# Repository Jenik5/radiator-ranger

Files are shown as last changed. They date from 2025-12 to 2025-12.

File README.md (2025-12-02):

# Radiátor Ranger

## 🥶➡️🔥 Chytrý termostat pro radiátorové hlavice (ESPHome)

**Radiátor Ranger** je chytrý regulátor pro radiátorové vytápění založený na ESP32-C3 a ESPHome.  
Je navržený pro termoelektrické hlavice typu **NO – normally open**, je spolehlivý, fail-safe a plně integrovatelný s Home Assistantem.

Zařízení vzniklo jako druhá generace původního domácího prototypu – tentokrát už s profesionální DPS, plnou diagnostikou a 3D tištěnou krabičkou.

---

## ✨ Hlavní vlastnosti

- Síťové napájení (bez baterií)  
- Fail-safe chování → při výpadku je radiátor *vždy plně otevřen*  
- Externí teplota z Home Assistanta  
- Automatický fallback na interní senzor  
- Detekce otevřeného okna (libovolný binární senzor z HA)  
- Ochrana proti zamrznutí  
- Režim topné sezóny  
- Boost (časovaný i trvalý), ovládaný tlačítkem  
- LED indikace stavu a chyb  
- 4 teplotní předvolby: Away, Sleep, Home, Comfort  
- Stavový výstup pro nadřazený systém (zda je potřeba topit)  
- Interní teplota radiátoru pro diagnostiku  

---

## 🧠 Jak to funguje

### Teplota  
- Primární teplotu poskytuje externí senzor z HA.  
- Při výpadku → automatický přechod na interní čidlo DS18B20.

### Otevřené okno  
- Otevření → zpoždění 2 minuty  
- Zavření → zpoždění 10 sekund  
- Při poklesu pod bezpečnou teplotu (např. 5 °C) se radiátor otevře kvůli nezámrzu.

### Topná sezóna  
- Mimo sezónu se ventil nezavírá → šetří se aktuátor i ventil.

### Stavová hlášení  
Termostat poskytuje stavy:  
*Vypnuto, Protizámrzný režim, Zapnuto, Topí, Větrání, Boost, Není topná sezóna.*

---

## 🧩 Ovládací prvky

### Tlačítko  
- krátký stisk → boost na 2 h  
- dvojstisk → trvalý boost  
- krátký stisk během boostu → vypnutí  
- dlouhý stisk → vypnutí / zapnutí termostatu

### LED  
- **zelená** – boost (blikání / trvale)  
- **červená** – chyby  
  - blikání = výpadek externího čidla  
  - trvale = výpadek interního čidla

---

## 🛠 Hardware Overview

### Schéma zapojení
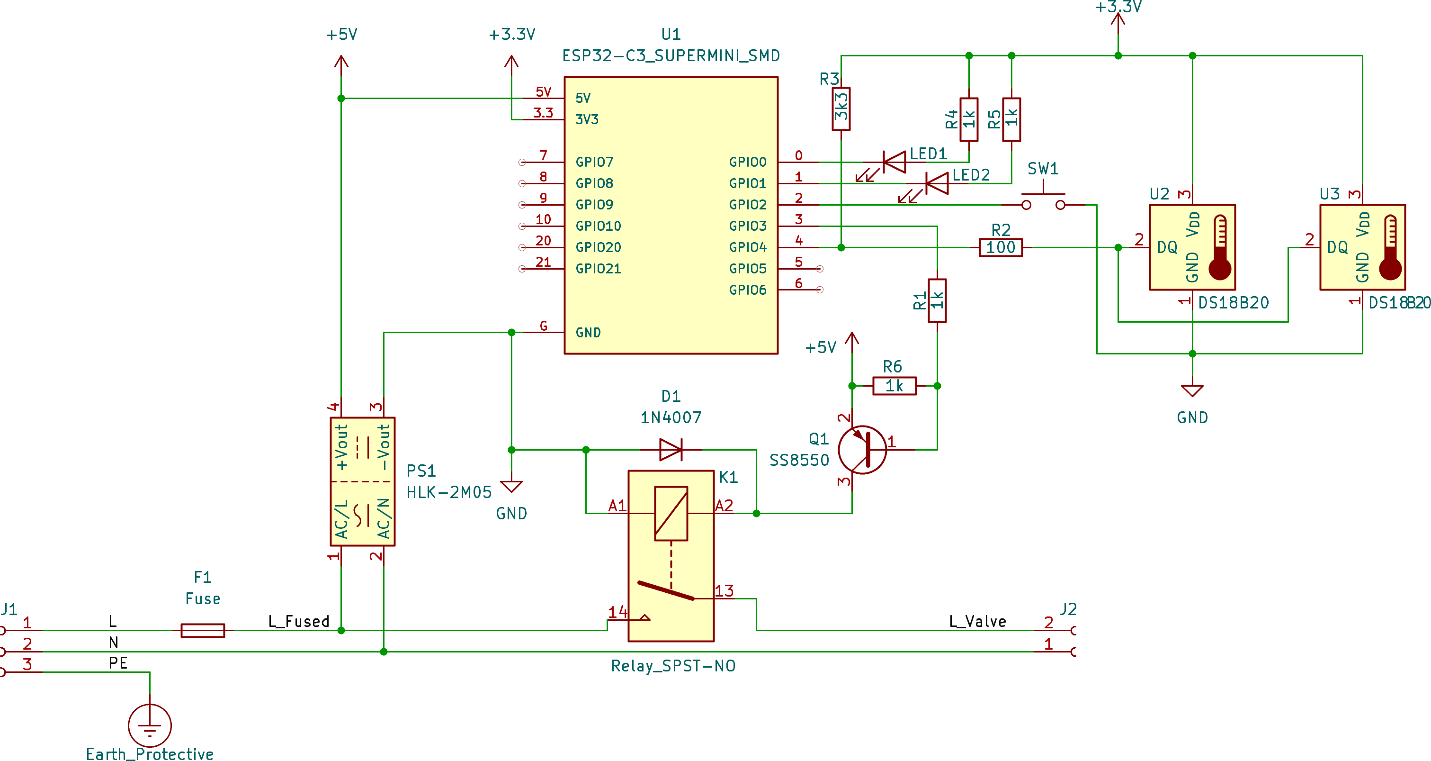
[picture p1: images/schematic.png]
Schematic


---

### Návrh DPS
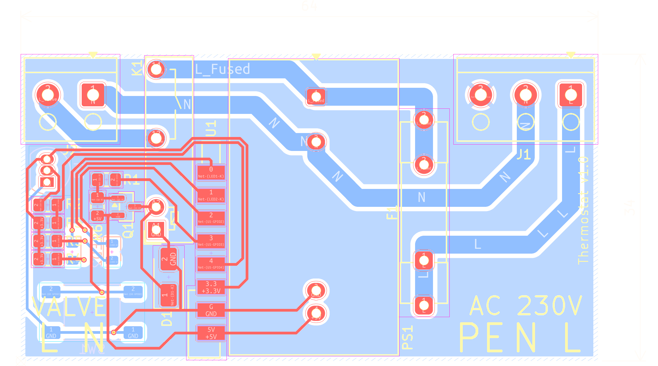
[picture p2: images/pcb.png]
PCB


---

### 3D náhled elektroniky
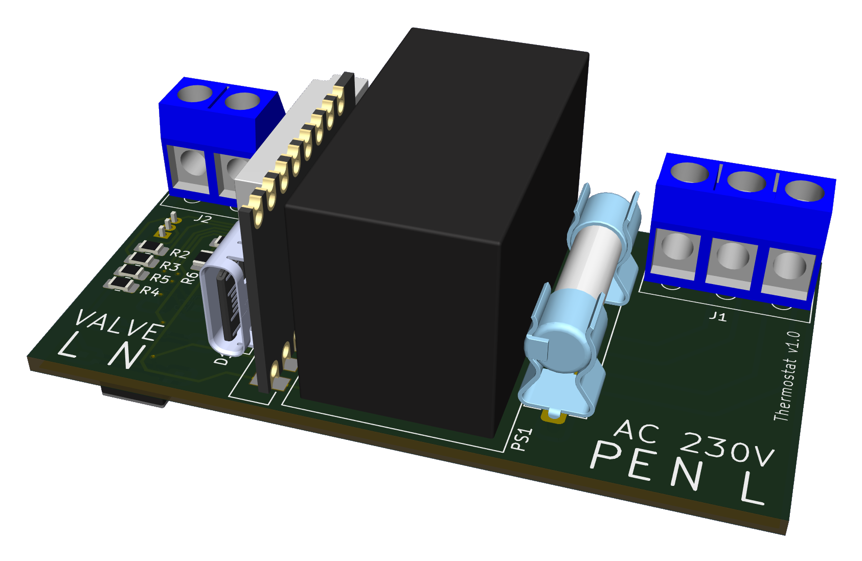
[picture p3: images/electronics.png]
Electronic module


---

### 3D tištěná krabička
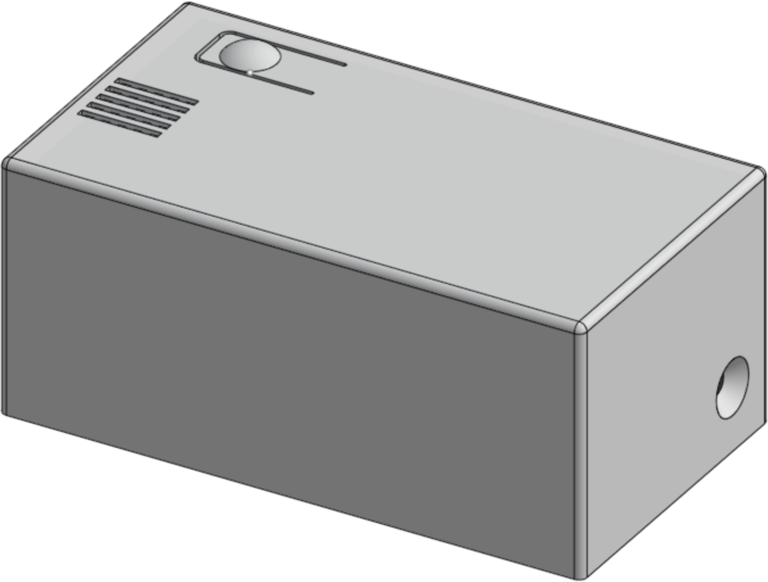
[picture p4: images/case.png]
Case


---

## 🧑‍💻 Software – ESPHome

Zařízení používá ESPHome s komponentou `climate` a vlastní sadou automatizací.

### Vybrané hodnoty konfigurace

```yaml
substitutions:
  device_internal_name: "radiator-v-predsini"
  device_suffix: "_v_predsini"
  device_friendly_name: "Radiátor v předsíni"

  device_sampling_time: "10s"

  led_green_brightness: "0.4"
  led_red_brightness: "0.6"

  dallas_diag: "0xab000000836f6328"
  dallas_fallback: "0xd500000083450828"

  external_temp_sensor: "sensor.teplomer${device_suffix}_temperature"
  heating_season_entity: "input_boolean.topna_sezona"
  open_window_entity: "input_boolean.dummy_zavreneho_okna"

  preset_temp_away: "10"
  preset_temp_sleep: "10"
  preset_temp_home: "15"
  preset_temp_comfort: "15"

  boost_minutes: "120"
  radiator_safe_temp: "5"
```

---

## 📦 Obsah repozitáře

```
/ESPHome      – ESPHome konfigurace  
/images        – obrázky pro README  
README.md      – tento soubor  
```

---

## 📝 Licence
MIT License © Jan Pruha

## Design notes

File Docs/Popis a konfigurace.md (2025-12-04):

# Radiátor Ranger – Dokumentace ovládacích prvků, senzorů a konfigurace

## Ovládací prvky

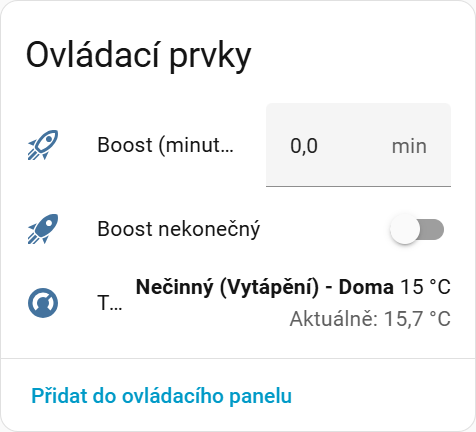
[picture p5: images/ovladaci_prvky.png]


### **Boost (minuty)**
Slouží k okamžitému přetlačení regulace termostatu a k aktivaci topení na maximální výkon po zadanou dobu.  
Během Boostu termostat dál normálně reguluje a pokud se mezitím změní režim (např. schedulerem), po ukončení Boostu bude pokračovat v aktuálně platném režimu.

### **Boost nekonečný**
Aktivuje nepřetržité nucené topení na maximální výkon, dokud není režim ručně ukončen.  
Používá se, pokud je třeba topit naplno bez časového omezení.

### **Stav topení (ovládací prvek)**
Otevře detail termostatu, který umožňuje:
- sledovat aktuální teplotu,  
- upravovat cílovou teplotu,  
- zobrazovat stav (topení / nečinný),  
- přepínat režimy.

Speciální interní stavy (např. Boost, větrání) se zde nezobrazují — ty poskytuje textový senzor.

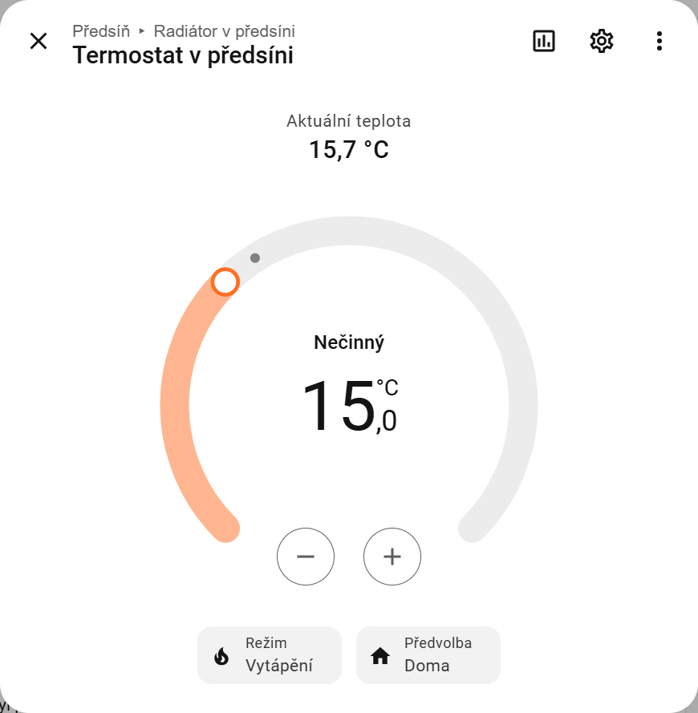
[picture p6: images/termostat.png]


---

## Senzory

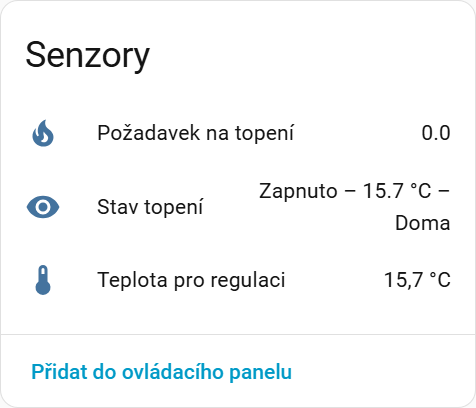
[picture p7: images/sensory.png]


### **Požadavek na topení**
Číselná hodnota **0.0 nebo 1.0**:
- **0.0** znamená, že termostat topení nepožaduje,  
- **1.0** znamená aktivní požadavek.

Je to takto navrženo proto, aby bylo možné snadno sečíst požadavky z více radiátorů a zjistit, kolik zařízení chce aktuálně topit.  
Příklad součtového senzoru je uveden v `/HomeAssistant/template.yaml`.

### **Stav topení (textový senzor)**
Podrobný textový popis toho, co termostat právě dělá.  
Zahrnuje například:

- **„Zapnuto – 15,7 °C – Doma“**  
- **„Vypnuto – Boost“**  
- **„Vypnuto – Otevřené okno“**  
- **„Neaktivní – Mimo topnou sezónu“**

Senzor se používá zejména v ovládacích panelech pomocí card-mod (viz `/HomeAssistant/tile.yaml`).

### **Teplota pro regulaci**
Teplota, kterou termostat skutečně používá pro regulaci.  
Zdroje mají tuto prioritu:

1. **Externí teplota** z HA  
2. **Interní prostorová teplota** (fallback)  
3. **Nouzová hodnota 0 °C**

---

## Diagnostika

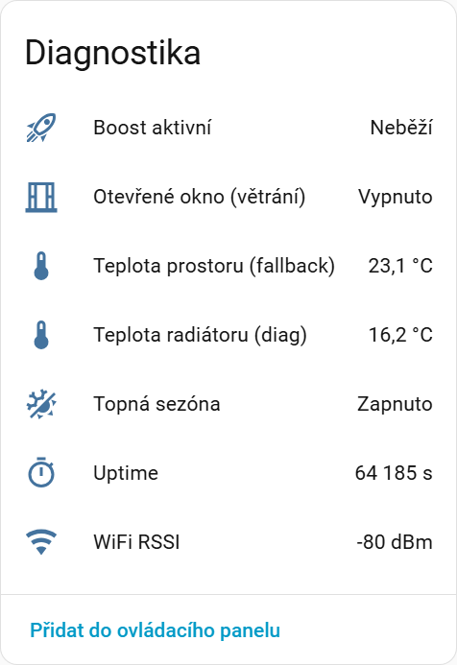
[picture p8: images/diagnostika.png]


### **Boost aktivní**
Zobrazuje, zda právě probíhá časový nebo nekonečný Boost, případně kolik času zbývá.

### **Otevřené okno (větrání)**
Externí signál z Home Assistantu, již se zpožděním filtrovaný  
(2 min při otevření, 10 s při zavření).

Má přímý vliv na chování termostatu — **převezme řízení a radiátor vypne**.  
Boost má vyšší prioritu, takže jeho aktivace otevřené okno přebije.

### **Teplota prostoru (fallback)**
Interní teplota z DS18B20 v těle zařízení.  
Používá se při výpadku externího senzoru.

### **Teplota radiátoru (diag)**
Interní teplota tělesa radiátoru (DS18B20).  
Zároveň slouží jako ochrana proti zamrznutí.

### **Topná sezóna**
Externí binární signál z Home Assistantu.

Slouží k odlehčení ventilu i aktuátoru v době, kdy je celé topení mimo provoz.  
Mimo topnou sezónu je ventil ponechán **otevřený**, protože zavírání by způsobovalo mechanické namáhání a aktuátor by navíc trvale odebíral přibližně **7 W** energie.

Topná sezóna má vyšší prioritu než Boost — pokud je mimo sezónu, bude ventil otevřený i při aktivním Boostu.

### **Uptime**
Čas od posledního restartu.

### **WiFi RSSI**
Síla WiFi signálu v dBm.

---

## Konfigurace

Většina chování termostatu se nastavuje pomocí bloku `substitutions` v ESPHome YAML konfiguraci.  
Tento blok umožňuje:

- přizpůsobit názvy entit a zařízení,
- napojit termostat na externí senzory a přepínače v Home Assistantu,
- nastavit jas LED indikace,
- definovat teplotní předvolby,
- upravit Boost a ochranné teploty,
- a zpřehlednit konfiguraci pomocí jednotné systematiky názvů.

Použití substitutions výrazně zjednodušuje přenositelnost mezi místnostmi.

---

### Interní a uživatelské názvy zařízení

```yaml
# Interní názvy zařízení
device_internal_name: "radiator-v-predsini"
device_suffix: "_v_predsini"
device_friendly_suffix: " v předsíni"
```

#### Doporučená systematika názvů

- **device_internal_name**  
  Interní název zařízení používaný ESPHome.  
  Doporučený formát:
  - bez mezer a bez diakritiky,
  - **pomlčky místo podtržítek** (ESPHome může mít s podtržítky problémy),
  - obsahuje přímo umístění,
  - příklad: `"radiator-v-predsini"`.

  Tento název se většinou automaticky vytvoří při zakládání jednotky v ESPHome.

- **device_suffix**  
  Sufix používaný v Home Assistantu při generování názvů entit.  
  Podtržítka jsou zde povolena a praktická.  
  Příklad: `"v_predsini"`.

- **device_friendly_suffix**  
  Lidsky čitelné jméno s mezerami a diakritikou.   
  Příklad: `"v předsíni"`.

Díky této systematice se automaticky odvodí i:

```yaml
device_wifi_name: "${device_internal_name}_wifi"
device_friendly_name: "Radiátor ${device_friendly_suffix}"
```

---

### Interval aktualizace diagnostiky

```yaml
device_sampling_time: "10s"
```

- Určuje, jak často se aktualizují stavové informace (WiFi RSSI, uptime…).  
- Hodnota ve formátu `10s`, `30s`, `1min`.  
- Doporučený interval je **10–60 sekund**.

---

### Jas stavových LED

```yaml
led_green_brightness: "0.4"  
led_red_brightness: "0.6"
```

- Rozsah 0.0–1.0 (0 = zhasnuto, 1 = maximální jas).  
- Slouží také k **vyvážení jasu obou LED**, protože různé barvy svítí rozdílně.
- Také je možné snížit jas na minimum v místnostech, kde by to rušilo.

---

### Adresy teplotních čidel DS18B20

```yaml
dallas_diag: "0xab000000836f6328"  
dallas_fallback: "0xd500000083450828"
```

Termostat používá dvě čidla:

- **dallas_diag** – čidlo na radiátoru (diagnostika, ochrana proti zamrznutí)  
- **dallas_fallback** – interní prostorové čidlo (náhradní teplota pro regulaci)

#### Postup při prvním spuštění

Po prvním startu se čidla **nepřihlásí**, protože nejsou známé jejich adresy.  
Adresy je potřeba přečíst z ESPHome logu:

```yaml
[14:43:52.798][C][gpio.one_wire:021]: GPIO 1-wire bus:  
[14:43:52.803][C][gpio.one_wire:022]:   Pin: GPIO4  
[14:43:52.810][C][gpio.one_wire:084]:   Found devices:  
[14:43:52.815][C][gpio.one_wire:086]:     0xd500000083450828 (DS18B20)  
[14:43:52.822][C][gpio.one_wire:086]:     0xab000000836f6328 (DS18B20)
```

Postup:

1. Adresy zapíšeme do substitutions  
2. Provedeme **druhý start**  
3. Ověříme správnost – jedno čidlo stiskneme mezi prsty a sledujeme, kterému senzoru stoupá teplota  
4. Pokud roste teplota druhému senzoru, adresy je potřeba vyměnit

---

### Externí teplotní a stavové entity z Home Assistantu

```yaml
external_temp_sensor: "sensor.teplomer_${device_suffix}_teplota"  
heating_season_entity: "input_boolean.topna_sezona"
open_window_entity: "binary_sensor.senzor_okna_${device_suffix}_otevirani"
#open_window_entity: "input_boolean.dummy_zavreneho_okna"
```

- **external_temp_sensor**  
  Externí prostorová teplota používaná pro regulaci.  
  Pokud dodržujeme systematiku názvů, název se **sám poskládá**.

- **heating_season_entity**  
  Binární entita určující topnou sezónu.  
  Typicky **pomocník (input_boolean)**.

- **open_window_entity**  
  Senzor otevřeného okna.  
  Při dodržení systematiky názvů se dá jednoduše odvodit správný název.  
  Pokud není reálný sensor okna, použije se dummy helper.

---

### Teplotní předvolby

```yaml
preset_temp_away:      "10"  
preset_temp_sleep:     "18"  
preset_temp_home:      "20"  
preset_temp_comfort:   "22"
```

Význam režimů:

- **Away** – útlum pro dlouhodobou nepřítomnost  
- **Sleep** – spánek. Vhodné i pro **krátkodobou nepřítomnost** (např. v práci)  
- **Home** – běžná teplota při pohybu v místnosti  
- **Comfort** – vyšší teplota při odpočinku (sedění, čtení…)

---

### Boost

```yaml
boost_minutes: "120"  
```

- **boost_minutes**  
  Délka časově omezeného Boostu.  
  Lze využít i prakticky, např. pro **sušení věcí** na radiátoru.

---

### Bezpečnostní teplota radiátoru

```yaml
radiator_safe_temp: "5"
```

- **radiator_safe_temp**  
  Minimální teplota radiátoru při větrání.  
  Pod touto hodnotou nehrozí ztráty tepla a zároveň se chrání proti zamrznutí.

---

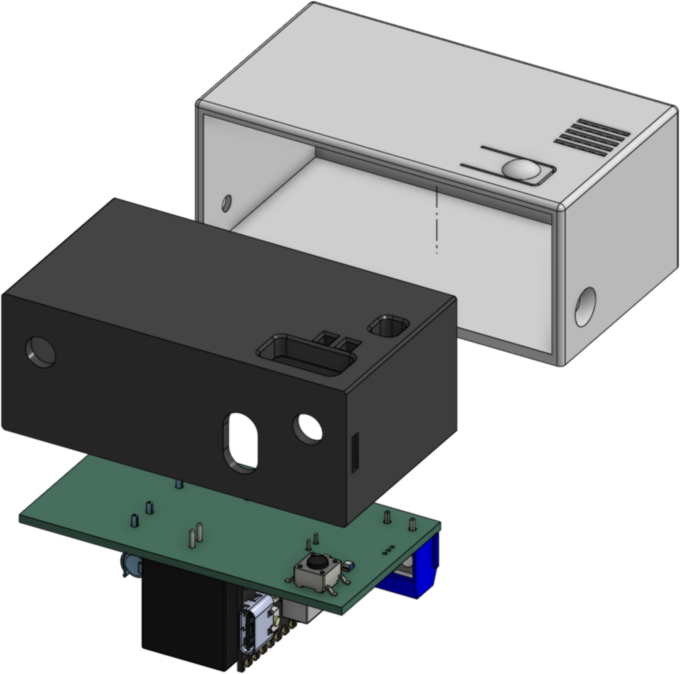
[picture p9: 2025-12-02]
images/exploded.png

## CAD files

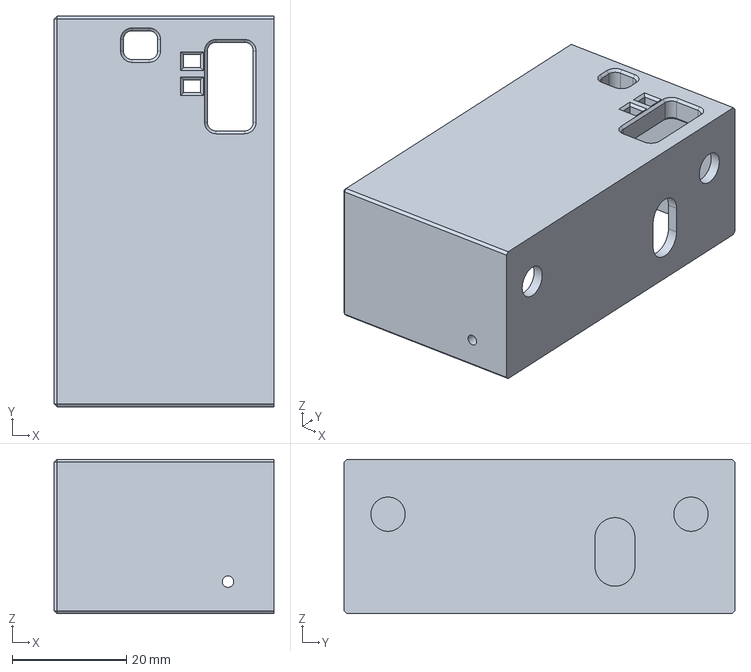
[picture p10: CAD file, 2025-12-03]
Case/Insert.step
38.4 x 68.4 x 27.0 mm

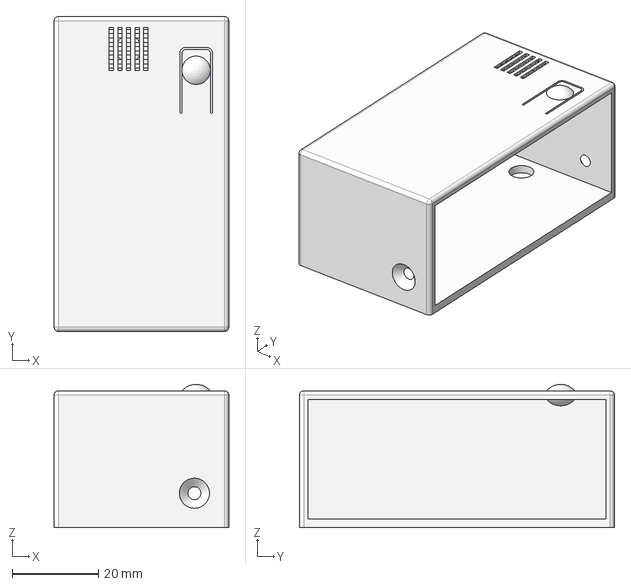
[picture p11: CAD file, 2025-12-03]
Case/Envelope.step
40.6 x 73.2 x 33.3 mm

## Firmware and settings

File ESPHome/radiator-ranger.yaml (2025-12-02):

################################################################################
# Substitution Variables – společné parametry pro celé zařízení
################################################################################
substitutions:
  # Interní názvy zařízení
  device_internal_name: "radiator-ranger"
  device_suffix: "_ranger"
  device_friendly_suffix: " ranger"

  # Odvozené názvy
  device_wifi_name: "${device_internal_name}_wifi"
  device_friendly_name: "Radiátor${device_friendly_suffix}"
  
  # Frekvence obnovování stavu wifi připojení a uptime
  device_sampling_time: "10s"

  # Jas LED (0.0–1.0)
  led_green_brightness: "0.4"
  led_red_brightness: "0.6"

  # Adresy teplotních čidel DS18B20 (diagnostika / fallback)
  dallas_diag: "0xab000000836f6328"
  dallas_fallback: "0xd500000083450828"

  # Externí teplota z HA – hlavní prostorové čidlo pro regulaci
  external_temp_sensor: "sensor.teplomer${device_suffix}_temperature"
  # Pro ladění je možné dočasně použít např.:
  # external_temp_sensor: "input_number.debug_temperature"

  # Externí binární senzor topné sezóny z HA
  heating_season_entity: "input_boolean.topna_sezona"

  # Externí binární senzor otevřeného okna či dveří z HA
  # Pokud reálný senzor není, použije se dummy helper stále „zavřeno“.
  open_window_entity: "input_boolean.dummy_zavreneho_okna"

  # Teploty pro jednotlivé předvolby termostatu (°C)
  preset_temp_away:      "10"
  preset_temp_sleep:     "10"
  preset_temp_home:      "15"
  preset_temp_comfort:   "15"

  # Doba trvání časově omezeného boostu
  boost_minutes: "120"

  # Minimální bezpečná teplota radiátoru při větrání (°C)
  # Pod touto hodnotou už nehrozí „topení z okna“, ale chráníme proti zamrznutí.
  radiator_safe_temp: "5"

################################################################################
# Globals – vnitřní stav zařízení
################################################################################
globals:
  # Boost režim:
  #   0  = boost neaktivní
  #  >0  = zbývající minuty boostu (časovaný režim)
  #  -1  = nekonečný boost (dokud se ručně nevypne)
  - id: boost_minutes
    type: int
    restore_value: yes
    initial_value: '0'

  # 0=OFF, 1=off_blink, 2=warn_blink, 3=error_steady
  - id: led_red_state
    type: int
    restore_value: no
    initial_value: '0'   

  # 0=OFF, 1=boost_blink, 2=boost_steady
  - id: led_green_state
    type: int
    restore_value: no
    initial_value: '0'   

################################################################################
# Board Configuration – ESP32 platforma
################################################################################ 
esp32:
  board: esp32-c3-devkitm-1
  variant: ESP32C3
  framework:
    type: arduino

esphome:
  name: ${device_internal_name}
  friendly_name: ${device_friendly_name}
  platformio_options:
    board_build.flash_mode: dio

  on_boot:
    priority: -10
    then:
      - delay: 10s
      - script.execute: update_valve_logic

################################################################################
# Enable logging
################################################################################
logger:

################################################################################
# Enable Home Assistant API
################################################################################
api:
  reboot_timeout: 0s
  encryption:
    key: !secret api_encryption_key

################################################################################
# OTA – aktualizace firmware
################################################################################
ota:
  platform: esphome
  password: !secret web_server_password

safe_mode:

################################################################################
# WiFi – připojení + fallback AP
################################################################################
wifi:
  networks:
    - ssid: !secret wifi_ssid
      password: !secret wifi_password

  # Fallback hotspot (captive portal) v případě výpadku WiFi
  ap:
    ssid: ${device_wifi_name}
    password: !secret web_server_password

captive_portal:

################################################################################
# Web Server – jednoduché webové UI (lokální)
################################################################################
web_server:

################################################################################
# Time – čas z Home Assistant
################################################################################
time:
  - platform: homeassistant

################################################################################
# Buses – DS18B20 (OneWire)
################################################################################
one_wire:
  - platform: gpio
    pin:
      number: GPIO4
      mode:
        input: true
        pullup: true
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

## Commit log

2025-12-02 Add initial configuration for radiator ranger device
    Added configuration for radiator ranger device including WiFi settings, temperature sensors, LED control, and valve logic.
2025-12-02 Add pcb.png image to ESPHome directory
2025-12-02 Add pcb.png image file
2025-12-02 Fix image filename case in README
2025-12-03 Add initial content to gerber.txt
2025-12-03 Add tile configuration for climate sensor
2025-12-03 Create template sensor for heating request sum
    Add a template sensor for heating request sum with details.
2025-12-04 Create documentation for Radiátor Ranger
    Added documentation for controls, sensors, and diagnostics of the Radiátor Ranger system.
2025-12-04 Enhance thermostat configuration documentation
    Added configuration details for thermostat setup, including naming conventions, temperature presets, and safety parameters.
